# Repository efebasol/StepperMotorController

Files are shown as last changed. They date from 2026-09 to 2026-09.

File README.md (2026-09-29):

# StepperMotorController

Stepper motor driver system based on TMC5160A + STM32. Long-term goal: a 6-axis robot arm controller made of 1 power distribution board, 1 main control board and 6 driver boards.

## Board status

| Board | Folder | Revision | Stage |
|---|---|---|---|
| Power board | `hardware/power` | Rev A | Schematic reviewed (ERC clean) · EMI input filter in progress (#65) · layout next |
| Driver board | `hardware/driver` | Rev A | Schematic |
| Firmware | `firmware` | – | Not started |

Tracking: [GitHub Project](https://github.com/users/efebasol/projects/12)

## Repository layout

```
hardware/
  power/     KiCad project – power board (48V in, brake chopper, 24V/5V buck, 12V/3V3 LDO, 24V eFuse) – see its README
  driver/    KiCad project – TMC5160 + MOSFET driver board
  lib/       Shared library: symbols/, footprints/, 3dmodels/
firmware/    STM32CubeIDE project
docs/        Calculations, decisions, notes
ci/          CI scripts (ERC/DRC, outputs, visual diff)
```

Libraries are resolved from inside the project (`${KIPRJMOD}/../lib/...`), so the project opens without broken parts on any machine.

> **Library rule:** don't leave parts linked to machine-local libraries (e.g. the KiCad PCM `PCM_JLCPCB-*` libs). Save them into `Step Motor Controller` (symbols/footprints) or use the standard `Device:R` / `Device:C` + an `LCSC` field. CI flags them as ERC warnings.

## Conventions

- **Commit messages:** `hw(power): ...`, `hw(driver): ...`, `fw(encoder): ...`, `docs: ...`, `ci: ...`
  Add `closes #NN` to close an issue from a commit.
- **Before committing:** save and close KiCad.
- **An ordered revision is frozen:** tag (`power-rev-a`) + GitHub Release (Gerber, BOM, CPL, schematic PDF). Later changes go to Rev B.
- **Branches:** hardware lives on `main`; experiments on `experiment/...`, firmware features on `feature/...`.
- Datasheets, tokens and key files are never committed.

## Issues & labels

- Templates: 🐞 Bug · ⚠️ Risk · 🛠️ Task (New issue).
- Labels: `hw` / `fw`, `power`, `schematic` / `layout`, `bug`, `risk`, `rev-a`.
- **`robot-arm-phase`** – deliberately deferred until the 6-axis arm; filter by this label when that phase starts.

## CI

- **Hardware CI** – on every push: ERC, DRC, schematic PDF, BOM, Gerber, CPL. Outputs are available as artifacts in the Actions tab.
  Once layout is done, set `STRICT: "1"` in `.github/workflows/hardware-ci.yml` → the run fails on errors.
- **Visual Diff** – before | after | diff images of changed schematics/PCBs. Can also be run manually against any tag/commit.

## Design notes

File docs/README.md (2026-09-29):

# docs

Design calculations, decisions and notes.

- Don't put datasheet PDFs here → link them instead (keeps the repo small).
- Calculation files (Excel/Python/Markdown) go here: FB dividers, UVLO, chopper threshold, track widths, loss/thermal estimates.

## Index

- [Power board – design notes (Rev A)](power-design-notes.md)

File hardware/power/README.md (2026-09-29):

# Power board

Rev A — single-motor bench prototype power board.
Feeds the driver board (48 V), the stepper motor brake (24 V) and the logic (5 V / 3V3).

## Blocks

| Block | Key parts | Notes |
|---|---|---|
| 48 V input | J2 XT60, F1 fuse, D4 SMBJ51A TVS, R21 NTC 5D-20 (inrush), D3 MBR10100 (reverse polarity), C20/C21 470 µF bulk | EMI input filter in progress (#65). LM74700 ideal diode deferred (#60) |
| Brake chopper | IC1 LM393 + U6 TL431B (±0.3 %), Q1 P40B10SL, U5 MCP1416 gate driver, R16 RX24 50 W 33 Ω (off-board, J1), D5 SS510 flyback | Turn-on ≈ 54.8 V nominal, ≤ 55.23 V worst case (0.1 % divider) < SMBJ51A 56.7 V. Capacity ≈ 1.66 A |
| 12 V LDO | U7 L78L12 (fed from 24 V) | Gate-driver supply only, not on any connector |
| 24 V buck | U1 TPS54360, L1 68 µH | Brake rail. UVLO start ~34 V / stop ~32 V |
| 24 V brake eFuse | U4 TPS16630 | PGOOD → D13, FLT# → J5 pin 5 (firmware #66) |
| 5 V buck | U3 TPS54360, L2 22 µH, 2×22 µF X7R out (C16, C27), comp. R10 4.22k / C18 27 nF / C17 220 pF | UVLO start ~34 V / stop ~32 V |
| 3V3 LDO | U2 AP2112K-3.3 | **max ~200 mA** (SOT-23-5 thermal); bigger LDO deferred (#61) |
| VBUS sense | R22 100k / R23 3.9k + 100 nF | 48 V → 1.80 V, ~82 V → 3.08 V. Firmware scaling #63 |
| Indicators | D6–D11 rail LEDs (48V, VM, 24V, 12V, 5V, 3V3), ~1.5 mA each | Silkscreen label next to each LED (#44) |

Design calculations: [`docs/power-design-notes.md`](../../docs/power-design-notes.md)

## Connectors

Board-to-board by **cables** (no stacking / backplane).

| Ref | Part | Function | Pinout |
|---|---|---|---|
| J2 | XT60PW-M | 48 V IN | 1: +48V · 2: GND |
| J3 | XT30PW-F | 48 V OUT (driver) | 1: VM · 2: GND |
| J4 | JST B2P-VH | 24 V BRAKE | 1: +24V · 2: GND |
| J5 | JST B5B-XH-A | LOGIC (main board) | 1: GND · 2: +5V · 3: +3V3 · 4: VBUS_SENSE · 5: TPS16630_FLT# |
| J1 | KF128 5.08 mm | Brake resistor R16 (off-board) | – |

Main-board side: 1 kΩ series resistor at the MCU ADC pin for VBUS_SENSE; one pull-up for FLT# (open-drain, active-low).

## Stackup

4 layers, 1.6 mm, JLCPCB.

| Layer | Copper | Use |
|---|---|---|
| L1 (F.Cu) | 2 oz | Power |
| L2 (In1.Cu) | 1 oz | Solid GND plane — never split (buck switching loops sit on top of it) |
| L3 (In2.Cu) | 1 oz | Signal + GND fill (keep it solid: it is the return path for L4) |
| L4 (B.Cu) | 2 oz | Power + signal |

**48 V, 24 V and SW nodes are routed on the 2 oz outer layers only** (inner 1 oz layers can't carry or dissipate that current). Vias between L1 and L4 are fine — current flows in the plated barrel.

> Order note: JLC's inner-layer default is 0.5 oz — select **1 oz** explicitly.

## Net classes

Values sized with IPC-2221 for 2 oz outer copper, ΔT ≈ 20 °C. Empty cells inherit `Default`.

| Net class | Clearance | Track width | Via size | Via hole | Nets / notes |
|---|---|---|---|---|---|
| `PWR_48V` | **0.6 mm** | 2.5 mm | 1.0 mm | 0.5 mm | 48 V bus. Main 10 A path (input → output connector) as pour where possible (10 A on 2 oz needs ≥2.4 mm) |
| `SW_NODE` | **0.6 mm** | 1.0 mm | – | – | Buck switch nodes (`SW_24V`, `SW_5V`, pattern `*SW_*`). Swing 0–48 V → 48 V clearance. Keep copper area minimal |
| `BOOT_NODE` | **0.6 mm** | 0.4 mm | – | – | Bootstrap nodes (`BOOT_24V`, `BOOT_5V`, pattern `*BOOT_*`). Rides on SW (up to ~SW + 8 V) → 48 V clearance, low current |
| `PWR_24V` | 0.25 mm | 0.8 mm | 0.8 mm | 0.4 mm | 24 V brake rail (motor brakes). Buck max 3 A → ≥0.45 mm |
| `PWR_5V` | 0.2 mm | 0.5 mm | 0.6 mm | 0.3 mm | 5 V logic rail; also `+12V` (L78L12 → MCP1416 gate driver, low current) |
| `PWR_3V3` | 0.2 mm | 0.4 mm | 0.6 mm | 0.3 mm | 3V3 LDO output |
| `GND` | 0.2 mm | 0.5 mm | 0.6 mm | 0.3 mm | Mostly planes/pours; tracks only for short links |
| `Default` | 0.2 mm | 0.25 mm | 0.6 mm | 0.3 mm | Signals (FB, comparator, gate drive, …) |

**FB nets** (`FB_24V`, `FB_5V`) stay in `Default` on purpose — see layout notes below.

Why 0.6 mm: IPC-2221 B2 (external, uncoated, 31–100 V). Between two classes KiCad applies the larger clearance, so every net next to 48 V automatically gets 0.6 mm.

Rules of thumb:
- ~1 A per 0.3 mm via → parallel vias on high-current transitions.
- Track width is the default, not a limit — widen freely, never go narrower.

### Layout notes

- **FB:** no net class needed — tiny current, width doesn't matter. What matters is placement: divider resistors right at the FB pin, short trace, never under or next to the SW node. A noisy FB makes the regulator output jitter.

### Global constraints (Board Setup → Constraints)

| Constraint | Value | Why |
|---|---|---|
| Min clearance | 0.15 mm | JLC 2 oz outer minimum |
| Min track width | 0.15 mm | JLC 2 oz outer minimum |
| Min via hole | 0.3 mm | |
| Min annular ring | 0.15 mm | |
| Copper to board edge | 0.5 mm | |

### Custom DRC rule (Board Setup → Custom Rules)

```
(version 1)
(rule "High-power nets: outer 2 oz layers only"
  (layer inner)
  (condition "A.NetClass == 'PWR_48V' || A.NetClass == 'PWR_24V' || A.NetClass == 'SW_NODE'")
  (constraint disallow track zone))
```

## Tracking

Issues: label `power` · Project: https://github.com/users/efebasol/projects/12

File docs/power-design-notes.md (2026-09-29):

# Power board – design notes (Rev A)

Key numbers behind the power board decisions. Issue numbers point to the discussion.

## Brake chopper threshold (#35, #36, #56)

Comparator input = divider R13 97.6k / (R17 4.75k ∥ R14 243k) against U6 TL431B (2.495 V).

- Nominal turn-on: 2.495 V × (1 + 97.6k / 4.659k) ≈ **54.8 V**
- Worst case (TL431B +0.3 %, divider tolerance, LM393 offset +9 mV):

| Divider tolerance | Worst-case turn-on | Margin to SMBJ51A V<sub>BR</sub> min 56.7 V |
|---|---|---|
| 1 % | 56.19 V | 0.51 V |
| **0.1 % (chosen)** | **55.23 V** | 1.47 V |

- Capacity: R16 33 Ω at ~55 V → **≈ 1.66 A**. Regen above that keeps raising the bus (6-axis case deferred, #54).
- The TVS (D4) only handles short transients; sustained regen is the chopper's job.

## Chopper gate drive (#31)

LM393 open-collector through 10k gave ~0.45 mA gate current (~100 µs linear region) and only ~4.54 V V<sub>GS</sub>.
→ MCP1416 gate driver from a dedicated 12 V LDO (L78L12, fed from 24 V, V<sub>IN</sub> max 30 V), 10 Ω gate resistor → V<sub>GS</sub> ≈ 12 V.

## 5 V buck output & compensation (#38)

Original C16 electrolytic (0.2–0.5 Ω ESR) broke the low-ESR assumption of the compensation (ESR zero ~10 kHz vs. ~35 kHz crossover, ~170 mV ripple).
→ 2 × 22 µF 25 V X7R 1210; type-II compensation R10 = 4.22 kΩ, C18 = 27 nF, C17 = 220 pF.

## UVLO

Both bucks: start ~34 V / stop ~32 V → the board will **not** start from a 24 V bench supply.

## VBUS_SENSE (#46, #63)

R22 100k / R23 3.9k → ratio 3.9 / 103.9 = 0.03754; source impedance ≈ 3.75 kΩ, 100 nF filter.

| V<sub>bus</sub> | V<sub>ADC</sub> |
|---|---|
| 48 V | 1.80 V |
| 55 V | 2.06 V |
| ~82 V (SMBJ51A clamp) | 3.08 V (< 3.3 V) |

Firmware: `V_bus = V_adc × 103.9 / 3.9`.

## Rail LEDs (#46)

~1.5 mA each. 48 V / VM LEDs use 33 kΩ: ~64 mW at 48 V, ~88 mW at 56 V (0805 = 125 mW).

## Track widths (#30)

IPC-2221, external 2 oz, ΔT ≈ 20 °C: 10 A → ≥2.4 mm, 3 A → ≥0.45 mm, 2 A → ≥0.26 mm. Inner 1 oz layers would need 2–5× wider → high-power nets stay on the outer layers (custom DRC rule). Full table: `hardware/power/README.md`.

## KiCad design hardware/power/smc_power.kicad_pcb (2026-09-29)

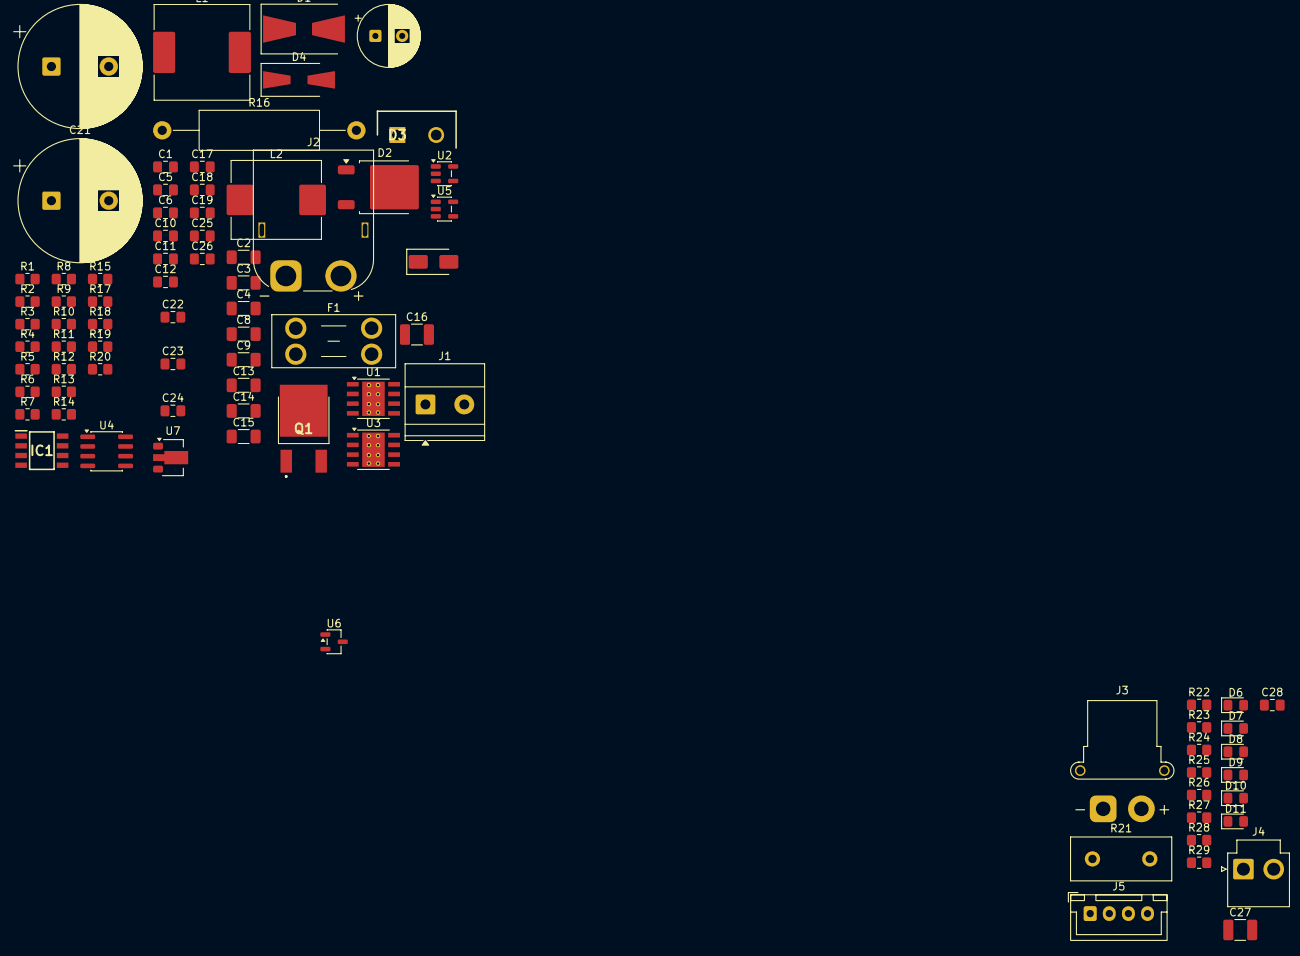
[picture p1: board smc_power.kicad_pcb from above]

Board: 2 copper layers, 85 parts (0 on the bottom side), 37 nets, no tracks yet.

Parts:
C1, C12: 100nF, 25V; C_0805_2012Metric_Pad1.18x1.45mm_HandSolder
C2, C3, C4, C13, C14, C15: 2.2uF, 100V; C_1206_3216Metric_Pad1.33x1.80mm_HandSolder
C5, C6: 1uF; C_0805_2012Metric_Pad1.18x1.45mm_HandSolder
C7: 68uF, 50V; CP_Radial_D8.0mm_P3.50mm
C8, C9: 10uF, 50V; C_1206_3216Metric_Pad1.33x1.80mm_HandSolder
C10: 24pF, 25V; C_0805_2012Metric_Pad1.18x1.45mm_HandSolder
C11: 5.1nF, 25V; C_0805_2012Metric_Pad1.18x1.45mm_HandSolder
C16, C27: 22µF 25V X7R 1210; C_1210_3225Metric_Pad1.33x2.70mm_HandSolder
C17: 220pF, 25V; C_0805_2012Metric_Pad1.18x1.45mm_HandSolder
C18: 27nF, 25V; C_0805_2012Metric_Pad1.18x1.45mm_HandSolder
C19: 100nF 100V; C_0805_2012Metric_Pad1.18x1.45mm_HandSolder
C20, C21: 470uF 100V; CP_Radial_D16.0mm_P7.50mm
C22: 0.33uF; C_0805_2012Metric_Pad1.18x1.45mm_HandSolder
C23: 0.1uF; C_0805_2012Metric_Pad1.18x1.45mm_HandSolder
C24: 4.7uF; C_0805_2012Metric_Pad1.18x1.45mm_HandSolder
C25: 100nF 25V; C_0805_2012Metric_Pad1.18x1.45mm_HandSolder
C26: 1uF 25V; C_0805_2012Metric_Pad1.18x1.45mm_HandSolder
C28: 100nF; C_0805_2012Metric_Pad1.18x1.45mm_HandSolder
D1: 100V 3A <= 850mV; D_SMB-SMC_Universal_Handsoldering
D2: 100V 5A; TO-252-2
D3: MBR10100; TO508P482X997X1956-2P
D4: SMBJ51A; D_SMA-SMB_Universal_Handsoldering
D5: SS510; D_SMA
D6: +48V; LED_0805_2012Metric_Pad1.15x1.40mm_HandSolder
D7: +VM; LED_0805_2012Metric_Pad1.15x1.40mm_HandSolder
D8: +24V; LED_0805_2012Metric_Pad1.15x1.40mm_HandSolder
D9: +12V; LED_0805_2012Metric_Pad1.15x1.40mm_HandSolder
D10: +5V; LED_0805_2012Metric_Pad1.15x1.40mm_HandSolder
D11: +3V3; LED_0805_2012Metric_Pad1.15x1.40mm_HandSolder
F1: 100V 10A; Fuseholder_Blade_Mini_Keystone_3568
IC1: LM393DR2GH; SOIC127P600X175-8N
J1: Screw_Terminal_01x02; TerminalBlock_Phoenix_MKDS-1,5-2-5.08_1x02_P5.08mm_Horizont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
J2: 48V Input; AMASS_XT60PW-M_1x02_P7.20mm_Horizontal
J3: 48V Output; AMASS_XT30PW-F_1x02_P2.50mm_Horizontal
J4: 24V Brake Output; JST_VH_B2P-VH_1x02_P3.96mm_Vertical
J5: Logic Output; JST_XH_B4B-XH-A_1x04_P2.50mm_Vertical
L1: 68uH; L_SXN_SMDRI125
L2: 22uH; L_Chilisin_BMRF00101040
Q1: P40B10SL; AOD4185
R1, R7: 523kR; R_0805_2012Metric_Pad1.20x1.40mm_HandSolder
R2: 348kR; R_0805_2012Metric_Pad1.20x1.40mm_HandSolder
R3, R9: 267kR; R_0805_2012Metric_Pad1.20x1.40mm_HandSolder
R4: 36.5kR; R_0805_2012Metric_Pad1.20x1.40mm_HandSolder
R5, R11: 18.7kR; R_0805_2012Metric_Pad1.20x1.40mm_HandSolder
R6: 12kR; R_0805_2012Metric_Pad1.20x1.40mm_HandSolder
R8: 60.4kR; R_0805_2012Metric_Pad1.20x1.40mm_HandSolder
R10: 4.22kR; R_0805_2012Metric_Pad1.20x1.40mm_HandSolder
R12: 11.5kR; R_0805_2012Metric_Pad1.20x1.40mm_HandSolder
R13: 97.6kR; R_0805_2012Metric_Pad1.20x1.40mm_HandSolder
R14: 243kR; R_0805_2012Metric_Pad1.20x1.40mm_HandSolder
R15: 10kR; R_0805_2012Metric_Pad1.20x1.40mm_HandSolder
R16: RX24, 50W, 33Ω; R_Axial_DIN0516_L15.5mm_D5.0mm_P25.40mm_Horizontal
R17: 4.75kR; R_0805_2012Metric_Pad1.20x1.40mm_HandSolder
R18: 10R; R_0805_2012Metric_Pad1.20x1.40mm_HandSolder
R19: 1kR; R_0805_2012Metric_Pad1.20x1.40mm_HandSolder
R20: 10k; R_0805_2012Metric_Pad1.20x1.40mm_HandSolder
R21: NTC_5_20; NTC_Disc_D13mm_W5.5mm_P7.5mm
R22: 100kΩ; R_0805_2012Metric_Pad1.20x1.40mm_HandSolder
R23: 3.9kΩ; R_0805_2012Metric_Pad1.20x1.40mm_HandSolder
R24, R25: 33kΩ; R_0805_2012Metric_Pad1.20x1.40mm_HandSolder
R26: 15kΩ; R_0805_2012Metric_Pad1.20x1.40mm_HandSolder
R27: 6.8kΩ; R_0805_2012Metric_Pad1.20x1.40mm_HandSolder
R28: 2kΩ; R_0805_2012Metric_Pad1.20x1.40mm_HandSolder
R29: 820Ω; R_0805_2012Metric_Pad1.20x1.40mm_HandSolder
U1, U3: TPS54360DDA; TI_SO-PowerPAD-8_ThermalVias
U2: AP2112K-3.3; SOT-23-5
U4: TL431D; SOIC-8_3.9x4.9mm_P1.27mm
U5: MCP1416; SOT-23-5
U6: TL431B_C54830630; SOT-23-3
U7: L78L12_SOT89; SOT-89-3

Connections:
+3V3: C6.1, J5.3, R29.1, U2.5 (VOUT)
+5V: C5.1, C16.1, C19.2, C27.1, IC1.6 (INPUT_B_2), IC1.8 (VCC), J5.2, L2.2, R8.1, R15.1, R19.2, R28.1, U2.1 (VIN), U2.3 (EN)
+12V: C23.1, C24.1, C25.2, C26.2, R27.1, U5.2 (Vdd), U7.1 (OUT)
+24V: C7.1, C8.1, C9.1, C22.1, J4.1, L1.2, R2.1, R26.1, U7.3 (IN)
+48V: F1.2, J2.1, R24.1
+VM: C2.1, C3.1, C4.1, C13.1, C14.1, C15.1, C20.1, C21.1, D4.1 (K), D5.1, J1.1, J3.1, R1.1, R7.1, R13.1, R16.1, R21.1, R22.1, R25.1, U1.2 (VIN), U3.2 (VIN)
/BOOT_5V: C12.1, U3.1 (BOOT)
/BOOT_24V: C1.1, U1.1 (BOOT)
/FB_5V: R8.2, R12.1, U3.5 (FB)
/FB_24V: R2.2, R6.1, U1.5 (FB)
/SW_5V: C12.2, D2.1 (K), L2.1, U3.8 (SW)
/SW_24V: C1.2, D1.1 (K), L1.1, U1.8 (SW)
/VBUS_SENSE: C28.1, J5.4, R22.2, R23.1
GND: C2.2, C3.2, C4.2, C5.2, C6.2, C7.2, C8.2, C9.2, C10.2, C11.2, C13.2, C14.2, C15.2, C16.2, C17.2, C18.2, C19.1, C20.2, C21.2, C22.2, C23.2, C24.2, C25.1, C26.1, C27.2, C28.2, D1.2 (A), D2.2 (A), D4.2 (A), D6.1 (K), D7.1 (K), D8.1 (K), D9.1 (K), D10.1 (K), D11.1 (K), IC1.4 (GND), IC1.5 (INPUT_B_1), J2.2, J3.2, J4.2, J5.1, Q1.3 (S), R3.2, R5.2, R6.2, R9.2, R11.2, R12.2, R17.2, R20.2, R23.2, U1.7 (GND), U1.9 (GNDPAD), U2.2 (GND), U3.7 (GND), U3.9 (GNDPAD), U4.1 (K), U5.4 (GND), U6.3 (A), U7.2 (GND)
unnamed: C11.1, R4.2
unnamed: C18.1, R10.2
unnamed: D3.2 (A), F1.1
unnamed: D3.1 (K), R21.2
unnamed: D6.2 (A), R24.2
unnamed: D7.2 (A), R25.2
unnamed: D8.2 (A), R26.2
unnamed: D9.2 (A), R27.2
unnamed: D10.2 (A), R28.2
unnamed: D11.2 (A), R29.2
unnamed: IC1.2 (INPUT_A_1), R19.1, U4.8 (REF), U6.1 (R), U6.2 (K)
unnamed: IC1.3 (INPUT_A_2), R13.2, R14.1, R17.1
unnamed: IC1.1 (OUTPUT_A), R14.2, R15.2, U5.3 (IN)
unnamed: D5.2, J1.2, Q1.2 (D)
unnamed: Q1.1 (G), R18.2, R20.1
unnamed: C10.1, R4.1, U1.6 (COMP)
unnamed: R1.2, R5.1, U1.3 (EN)
unnamed: R3.1, U1.4 (RT/CLK)
unnamed: C17.1, R10.1, U3.6 (COMP)
unnamed: R7.2, R11.1, U3.3 (EN)
unnamed: R9.1, U3.4 (RT/CLK)
unnamed: U4.2 (A), U4.3 (A), U4.6 (A), U4.7 (A)
unnamed: R18.1, U5.5 (OUT)

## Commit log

2026-09-23 project setup
    [AM26LS32AID.stp, AOD4126.stp, LM393DR2GH.stp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]
2026-09-23 hw(power): WIP schematic updates (pre-restructure snapshot)
    [smc_power.kicad_sch]
2026-09-23 chore: restructure repo (hardware/, firmware/, docs/), project-local libs, CI + visual diff
    - smc_board -> hardware/{power,driver,lib}
    - Step Motor Controller lib now resolved via ${KIPRJMOD}/../lib (no global path)
    - 3D model paths made project-relative
    - .gitignore: KiCad 10 .history, STM32CubeIDE outputs, secrets
    - CI: ERC/DRC + fab/doc outputs (kicad-cli, KiCad 10)
    - Visual diff workflow (before | after | diff)
    [smc_driver.kicad_pcb, smc_driver.kicad_sch, smc_power.kicad_pcb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]
2026-09-23 ci: use kicad 10.0-full image with standard libraries for accurate ERC
2026-09-23 docs: switch all repo-facing text to English (README, templates, CI, gitignore, lib tables)
2026-09-24 docs(power): document stackup, net classes and DRC rules, refs #30
2026-09-24 hw(power): net classes, 4-layer stackup and inner-layer DRC rule, closes #30
    [smc_power.kicad_pcb]
2026-09-24 hw(power): add MCP1416 gate driver + 12V LDO for brake chopper Q2, 10R gate resistor, closes #31
    [smc_power.kicad_sch]
2026-09-24 hw(power): RX24 50W brake resistor + SS510 flyback diode, closes #32
    [smc_power.kicad_sch]
2026-09-27 hw(power): label SW/BOOT/FB nets, add SW_NODE/BOOT_NODE classes, ERC clean, closes #34
    [smc_power.kicad_pcb, smc_power.kicad_sch]
2026-09-27 ci: load KiCad default global library tables (fixes false lib_symbol/footprint_link ERC warnings)
2026-09-27 hw(power): move +VM and SS510 into project library, SS510 footprint -> Diode_SMD:D_SMA (no machine-local libs)
    [smc_power.kicad_pcb, smc_power.kicad_sch]
2026-09-27 hw(lib): use KiCad 10 symbol-library file version (20251024)
2026-09-27 hw(power): SMBJ51A TVS, fix TL431B (U4) orientation + REF-K, SOT-23 footprint, refs #35 #36 #37
    [smc_power.kicad_pcb, smc_power.kicad_sch]
2026-09-28 hw(power): 5V output 2x22uF X7R + recompensation, inrush NTC, C22-24 footprints, refs #35, closes #38
    [smc_power.kicad_pcb, smc_power.kicad_sch]
2026-09-28 hw(power): minor review items (NTC 5D-20 + footprint, notes), AP2112K load note, refs #35
    [smc_power.kicad_sch]
2026-09-28 hw(power): NTC R21 LCSC -> C122780 (5D-20), refs #48
    [smc_power.kicad_sch]
2026-09-28 hw(power): connectors J1-J5 (XT60/XT30/VH/XH/KF128), off-board brake resistor, VBUS_SENSE divider, pinout note; VBUS parts moved to project lib, closes #45
    [smc_power.kicad_sch]
2026-09-28 hw(power): VBUS divider R23 3.9k, rail LEDs (48V/VM/24V/12V/5V/3V3); JLC resistors moved to project lib, refs #46
    [smc_power.kicad_sch]
2026-09-28 hw(power): VM LED power symbol from project lib
    [smc_power.kicad_sch]
2026-09-29 hw(power): TPS16630 eFuse on 24V brake output (PGOOD LED, FLT# on J5.5), J5 -> B5B-XH-A, JLC parts to project lib, closes #55
    [smc_power.kicad_pcb, smc_power.kicad_sch]
2026-09-29 hw(power): TPS16630 symbol pin types (passive / open-drain FLT#, PGOOD), J5 pinout note pin 5, refs #55
    [smc_power.kicad_sch]
2026-09-29 docs: update READMEs (power blocks, connectors, labels, library rule) + power design notes
2026-10-14 docs(power): chopper turn-off lower bound and PSU <= 52 V requirement, refs #56
2026-10-14 hw(power): 48V input DM pi-filter (L4 2.2uH ETQP4M2R2KVK, C34/C35 2.2uF 100V X7R), closes #65
2026-10-14 docs(power): EMI pi filter in block table and design notes, refs #65
2026-10-14 hw(power): +VM symbol from project lib, L4 LCSC field, refs #48
2026-10-23 hw(power): final review fixes — TL431 REF-K via 0R, eFuse ILIM, notes; JLC resistors to project lib, refs #67
2026-10-23 hw(power): re-apply +VM project-lib symbol and L4 LCSC field (lost on save), refs #67
2026-10-23 docs(power): eFuse ILIM and TL431 0R link in block table, refs #67
2026-10-23 hw(power): 4-layer 2oz/1oz stackup, PCB synced from schematic, refs #39
2026-10-23 hw(power): re-apply project-lib fixes overwritten by KiCad save (+VM, R30/R36, L4 LCSC), refs #39
2026-10-23 hw(power): enter Board Setup constraints (clearance/track/annular 0.15, via 0.6/0.3), refs #39
    Claude-Session: https://claude.ai/code/session_01SoMHYQYx4yCFML8vht6Kpa
2026-10-24 hw(power): board outline, mounting holes, zones, floorplan and chopper/buck/LDO layout, refs #39 #40 #41 #42 #43
    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
2026-10-27 hw(power): complete layout (all blocks placed and routed), refs #39 #40 #41 #42 #43 #68
    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
2026-10-27 hw(power): J4 +/- silkscreen, refs #39
    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
2026-10-27 hw(power): sync footprint fields (Description, Datasheet, LCSC, ...) from schematic, refs #39
    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
2026-10-27 hw(power): Q1 drain tab 5x5 via array, refs #40
    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
2026-10-27 hw(power): CHOP_DRAIN copper under Q1 on B.Cu, refs #40
    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
2026-10-27 hw(power): U4 EP thermal vias, zones filled, refs #68
    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
2026-10-27 hw(power): J3 +/- polarity silkscreen, refs #44
    Claude-Session: https://claude.ai/code/session_018dhsxeAre3KftxKezGsQwA
2026-10-27 hw(power): final layout touch-ups, refs #44
    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
2026-10-27 hw(power): JLCPCB 2oz DFM rules in custom DRC, refs #47
    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
2026-10-27 hw(power): LCSC part numbers for 67 parts, 0.1% R13/R17, R14 1% (hysteresis), refs #48
    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
2026-10-27 hw(power): R21 -> MF72 5D13 (fits 7.5 mm footprint), Q1 -> AOD4126, refs #48
    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
2026-10-27 ci: JLCPCB export (Gerber/drill zip, SMT BOM + CPL, hand-solder list); fix U1/U3/U4 3D model paths, refs #48 #49 #51
    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
2026-10-27 docs(power): NTC 5D13, Q1 AOD4126, R14 1% rationale, refs #48
    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
2026-10-27 ci+docs: release workflow (tag power-rev-*) and JLC order sheet, refs #51 #52
    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
2026-10-27 hw(power): J2/J3 polarity silkscreen per nets (remove footprint +/- text), fixes #69
    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
2026-10-27 hw(power): readable part values (LED colour, connector/fuse part numbers); silkscreen labels kept as text, refs #48
    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
